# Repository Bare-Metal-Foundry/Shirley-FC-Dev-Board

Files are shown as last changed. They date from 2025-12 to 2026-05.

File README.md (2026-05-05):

<!--
This project follows atomic documentation.
Each subsystem is documented independently.
All configs are stored in YAML.
-->

# Shirley - Flight Controller Development Board

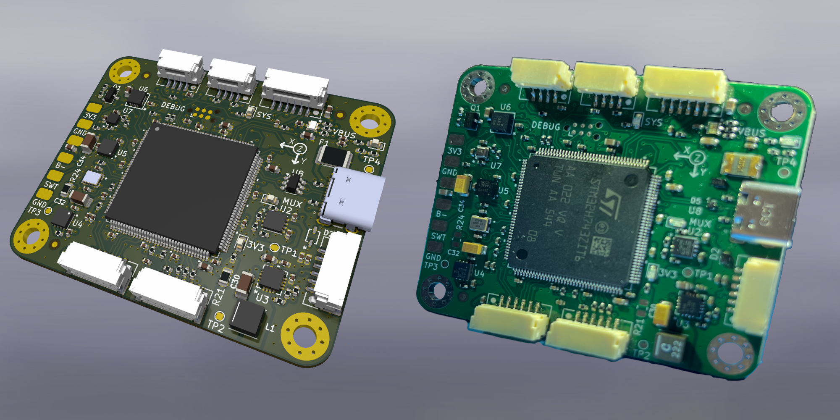
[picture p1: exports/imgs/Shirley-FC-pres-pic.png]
board_render


Shirley is high-performance flight controller hardware platform built around the STM32H743 microcontroller, designed for custom firmware development and compatibility with existing flight stacks.

## Features

### Core Hardware
- **MCU**: STM32H743ZIT6 (480 MHz Cortex-M7, FPU, DSP)
- **IMU**: ICM-40609-D (6-axis, low-noise, up to 32 kHz ODR)
- **Magnetometer**: MMC5983MA (18-bit precision with degaussing)
- **Barometer**: BMP390 High-precision altitude sensing
- **Storage**: SD card socket for flight data logging

### Power System
- **Input**: 5V via standard Pixhawk power module
- **Architecture**: 5V MUX + Dual 3.3V rails (digital + filtered analog) for low-noise sensor operation
- **Protection**: ESD protection on USB-C and power connector

### Connectivity
- **Motor Control**: 4x ESC outputs
- **RC Input**: Standard RC receiver connection
- **GPS**: Dedicated UART interface
- **Telemetry**: Bidirectional radio module support
- **USB**: Full-speed OTG for configuration and debugging
- **CAN**: FDCAN interface (in the GPS connector)
- **Debug**: Tag-Connect SWD/SWO interface

Note: All connectors are GH1.25 connectors

## Documentation

This project uses atomic documentation - each subsystem is documented independently in `/docs`:

- **[Hardware Overview](docs/hardware/overview.md)** - System architecture and block diagrams
- **[Power Architecture](docs/hardware/power-architecture.md)** - Power rail design and specifications
- **[Design Decisions](docs/hardware/design-decisions.md)** - Component selection rationale
- **[STM32 Subsystem](docs/hardware/stm32-subsystem/)** - MCU peripheral configuration

All hardware configurations are defined in machine-readable YAML format in `/config`:
- **[pinout.yaml](config/pinout.yaml)** - Complete STM32H743 pin assignments
- **[power.yaml](config/power.yaml)** - Power rail specifications and architecture

## Repository Structure

```
├── hardware/KiCad/FC_v1.0/         # KiCad 9.0 schematics and PCB layout
├── firmware/STM32 Cube IDE/        # STM32CubeMX configuration
├── config/                         # YAML configuration files
├── docs/                           # Atomic documentation by subsystem
├── docs/hardware/exports/          # exports and version history
└── resources/datasheets/           # Component datasheets organized by type
```

## Getting Started

### Overview
1. Exported schematics and renders can be found here: `exports/`
2. The different versions designed and produced are detailed here: `exports/versions-history.md`
3. An overview of the design can be found here: `docs/hardware/overview.md`

### Hardware Design
1. Open schematics in **KiCad 9.0**: `hardware/KiCad/FC_v1.0/FC-proto.kicad_sch`
2. Review hierarchical subsystem sheets (power, interfaces, sensors)
3. Custom component footprints are in `hardware/cad-layout/`

### Firmware Development
1. Open STM32CubeMX project: `firmware/STM32 Cube IDE/FC-proto-El.ioc`
2. Pin assignments match `config/pinout.yaml`
3. Connect debugger via Tag-Connect cable (SWD: PA13/PA14, SWO: PB3)

## Design Philosophy

This first revision prototype prioritizes:
- **Development-friendly**: Easy debugging via Tag-Connect, USB, and comprehensive logging
- **Compact Board**: Compact board to fit in smaller frames
- **Signal quality**: Low-noise analog power domain for sensor accuracy
- **Integration**: Integration with existing pixhawk drone hardware

## Flight Stack Compatibility

The hardware pinout and peripheral configuration supports:
- **PX4** - Full feature compatibility
- **Ardupilot** - Standard Pixhawk interface support
- **Betaflight** - High-rate control loop capability

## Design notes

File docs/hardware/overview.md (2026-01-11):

# Hardware Overview

## System Architecture

Shirley is a high-performance flight controller development board built around the **STM32H743ZIT6** microcontroller (480 MHz Cortex-M7 with FPU and DSP). The hardware architecture prioritizes signal quality, compact design, and seamless integration with existing Pixhawk drone hardware.

## Core Components

### Microcontroller
- **STM32H743ZIT6**: 480 MHz Cortex-M7, 2 MB Flash, 1 MB RAM
- Complete peripheral assignments in [`config/pinout.yaml`](../../config/pinout.yaml)
- HSE: 16 MHz external crystal oscillator

### Embedded Sensors
- **ICM-40609-D** (IMU): 6-axis low-noise sensor, up to 32 kHz ODR, SPI5 interface
- **MMC5983MA** (Magnetometer): 18-bit precision with built-in degaussing, SPI4 interface
- **BMP390** (Barometer): High-precision altitude sensor, I2C2 interface

See [`docs/hardware/design-decisions.md`](design-decisions.md) for sensor selection rationale.

### Storage
- **SD Card**: SDMMC1 interface (4-bit mode) for flight data logging

## Power Architecture

The power system uses a hierarchical rail structure optimized for low-noise sensor operation:

```
Pixhawk Power Module (5V, 2-3A)
  ├─ EXT_5V → External peripherals (GPS, telemetry) - bypasses MUX
  └─ TPS2113A MUX → 5V_SYS (2.5A, onboard only)
       ├─ TPS62130 Buck → 3V3_DIG (2A) → STM32, peripherals, interfaces
       └─ TPS7A2133 LDO → 3V3_ANA (500mA) → Sensors, STM32 VDDA
```

**Key Design Features:**
- **Dual 3.3V rails**: Separate digital (buck) and analog (LDO) domains
- **5V Power MUX**: The MCU and onboard sensors can be supplied by USB-C, Power connector or both
- **External peripheral bypass**: GPS and telemetry connect directly to EXT_5V, preserving 5V_SYS budget for onboard systems
- **Ultra-low-noise analog**: TPS7A2133 LDO provides 7.7µVRMS noise for precision sensors

Full specifications in [`config/power.yaml`](../../config/power.yaml).

## Peripheral Interfaces

### Power Connector (JST GH 6-pin)
- **Connector**: SM06B-GHS-TB
- **EXT_5V**: Primary power input from Pixhawk power module (5.0V, 2-3A)
- **Battery Monitoring**: Voltage sense (ADC1_INP2: PF11), Current sense (ADC1_INP3: PA6)
- Powers external peripherals directly (GPS, telemetry bypass MUX)

### USB Type-C
- **Interface**: USB_OTG_FS (Full Speed)
- **Pins**: DM: PA11, DP: PA12, VBUS: PA9
- Secondary power input for development/testing

### Debug Tag Connect (TC2030)
- **Interface**: SWD programming and debugging
- **Pins**: SWDIO: PA13, SWCLK: PA14, SWO: PB3
- Tag-Connect 6-pin no-legs connector for compact debugging

### RC Connector (JST GH)
- **Interface**: USART6
- **Pins**: TX: PC6, RX: PC7
- RC receiver input (SBUS, PPM, etc.)

### ESC Connector (JST GH)
- **Interface**: TIM1 (4 channels)
- **Pins**: CH1: PE9, CH2: PE11, CH3: PE13, CH4: PE14
- Motor outputs supporting PWM and DShot protocols

### Telemetry Connector (JST GH)
- **Interface**: UART4 with hardware flow control
- **Pins**: TX: PA0, RX: PA1, CTS: PB0, RTS: PB14
- Telemetry radio communication

### GPS Connector (JST GH)
- **Interfaces**: UART8 + FDCAN1
- **UART8 Pins**: TX: PE1, RX: PE0
- **FDCAN1 Pins**: TX: PB9, RX: PD0
- Supports both serial and CAN GPS modules

### I2C Connector (JST GH)
- **Interface**: I2C1
- **Pins**: SDA: PB7, SCL: PB6
- External I2C peripherals (e.g., external compass)

### Extra Pad Connectors
- **UART5**: TX: PB13, RX: PB12 (Mini Pad Out)
- **USART2**: TX: PA2, RX: PA3 (Pad Out)
- **I2C4**: SDA: PF15, SCL: PF14 (Pad Out)
- **ADC2**: INP2: PF13, INP4: PC4, INP5: PB1 (Analog inputs)
- **GPIOs**: PE15, PB10, PB11 (General purpose expansion)

Complete pin assignments in [`config/pinout.yaml`](../../config/pinout.yaml).

## Connectivity Standards

All connectors use **JST GH 1.25mm** standard (except for debug) for Pixhawk compatibility:
- Power: SM06B-GHS-TB (6-pin)
- Peripherals: Various GH connectors
- Debug: TC2030 (Tag-Connect 6 Pin)

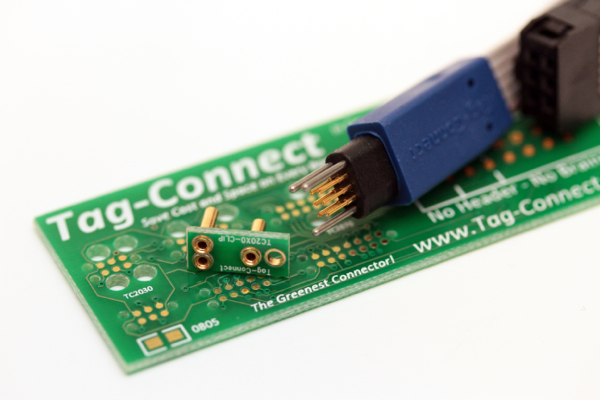
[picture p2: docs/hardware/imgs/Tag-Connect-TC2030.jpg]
tc2030_connector


## Design Priorities

This first revision prototype focuses on:
1. **Signal quality**: Clean analog power domain for sensor accuracy
2. **Development-friendly**: Tag-Connect debugging, USB access, comprehensive logging
3. **Compact form factor**: Fits smaller drone frames
4. **Pixhawk integration**: Standard interfaces and connectors

## Flight Stack Compatibility

The hardware supports multiple flight stacks:
- **PX4**: Full feature compatibility
- **ArduPilot**: Standard Pixhawk interface support
- **Betaflight**: High-rate control loop capability

## Related Documentation

- **[Power Architecture](power-architecture.md)**: Detailed power subsystem design
- **[Design Decisions](design-decisions.md)**: Component selection rationale
- **[STM32 Subsystem](stm32-subsystem/)**: MCU peripheral configuration
- **Configuration Files**: [`pinout.yaml`](../../config/pinout.yaml), [`power.yaml`](../../config/power.yaml)

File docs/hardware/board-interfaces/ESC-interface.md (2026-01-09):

# STM32CubeIDE - Configuring TIM for ESC PWM Control
## Step-by-Step Guide for STM32H743ZIT6

This guide shows you how to configure a timer in STM32CubeIDE to generate 4 PWM signals for ESC motor control.

---

## 📋 Part 1: Opening STM32CubeMX Configuration

### Step 1: Open Your Project
1. Open your project in **STM32CubeIDE**
2. In the Project Explorer, double-click on the **`.ioc`** file
   - Usually named something like `YourProjectName.ioc`
   - This opens the STM32CubeMX graphical configurator

---

## 🎯 Part 2: Selecting and Configuring GPIO Pins

### Step 2: Select Timer Pins in Pinout View

1. You should now see the **Pinout & Configuration** tab
2. Look at the chip diagram in the center

3. **Find and configure the pins for TIM1:**

   **Option A - Click pins directly on chip diagram:**
   - Click on pin **PE9** → Select **TIM1_CH1**
   - Click on pin **PE11** → Select **TIM1_CH2**
   - Click on pin **PE13** → Select **TIM1_CH3**
   - Click on pin **PE14** → Select **TIM1_CH4**

   **Option B - Use the pin assignment tool:**
   - Go to **Pinout view** (left panel)
   - Expand **Timers** → **TIM1**
   - For each channel, click the dropdown:
     - **Channel1** → Select pin **PE9**
     - **Channel2** → Select pin **PE11**
     - **Channel3** → Select pin **PE13**
     - **Channel4** → Select pin **PE14**

4. The pins should now be **green** on the chip diagram, indicating they're configured

### Visual Guide - What You Should See:
```
STM32H743ZIT6 Chip Diagram:
┌─────────────────────────┐
│                         │
│  PE9  (green) ← TIM1_CH1│  Motor 1
│  PE11 (green) ← TIM1_CH2│  Motor 2
│  PE13 (green) ← TIM1_CH3│  Motor 3
│  PE14 (green) ← TIM1_CH4│  Motor 4
│                         │
└─────────────────────────┘
```

---

## ⚙️ Part 3: Timer Configuration

### Step 3: Configure TIM1 in PWM Mode

1. In the **Categories** panel (left side), find and click **Timers** → **TIM1**

2. In the **TIM1 Mode and Configuration** panel, configure each channel:

   **Set Channel Modes:**
   - **Channel 1**: Select **PWM Generation CH1**
   - **Channel 2**: Select **PWM Generation CH2**
   - **Channel 3**: Select **PWM Generation CH3**
   - **Channel 4**: Select **PWM Generation CH4**

   *(Click the dropdown next to each channel and select "PWM Generation CHx")*

### Step 4: Configure Timer Parameters

Now click on the **Parameter Settings** tab (still in TIM1 configuration):

#### Counter Settings:
```
┌─────────────────────────────────────────────┐
│ Parameter              │ Value              │
├─────────────────────────────────────────────┤
│ Prescaler (PSC)        │ 199                │
│ Counter Mode           │ Up                 │
│ Counter Period (ARR)   │ 19999              │
│ Internal Clock Div     │ No Division        │
│ Auto-reload preload    │ Enable             │
└─────────────────────────────────────────────┘
```

**Enter these values:**
- **Prescaler**: `199`
  - *Why?* 200MHz / (199+1) = 1MHz = 1μs tick resolution
- **Counter Period (AutoReload Register)**: `19999`
  - *Why?* 20,000 ticks × 1μs = 20ms = 50Hz (standard for ESC)
- **Counter Mode**: `Up`
- **auto-reload preload**: `Enable`

#### PWM Generation Channel Settings:

For **each channel** (CH1, CH2, CH3, CH4), configure:

```
┌─────────────────────────────────────────────┐
│ Parameter              │ Value              │
├─────────────────────────────────────────────┤
│ Mode                   │ PWM mode 1         │
│ Pulse (CCRx)          │ 1000               │
│ Output Compare Preload │ Enable             │
│ Fast Mode              │ Disable            │
│ CH Polarity            │ High               │
└─────────────────────────────────────────────┘
```

**For Channel 1 (repeat for CH2, CH3, CH4):**
- **Mode**: `PWM mode 1`
- **Pulse (CCR1)**: `1000`
  - *Why?* Starting value = 1000μs = minimum throttle (safe)
- **Output Compare Preload**: `Enable`
- **Fast Mode**: `Disable`
- **CH Polarity**: `High`

### Step 5: Configure Clock Source

1. Still in TIM1 settings, click on **Clock Source** tab
2. Select: **Internal Clock**

### Step 6: Advanced Settings (Important for TIM1!)

TIM1 is an **Advanced Control Timer** and requires additional configuration:

1. Click on **Advanced settings** section (or look for it in the Parameter Settings)

2. Configure **Break and Dead Time**:
   ```
   ┌─────────────────────────────────────────────┐
   │ Off-State Selection for Run    │ Disable   │
   │ Off-State Selection for Idle   │ Disable   │
   │ Lock Configuration             │ OFF       │
   │ Break Input State              │ Disable   │
   │ Automatic Output Enable        │ Disable   │
   └─────────────────────────────────────────────┘
   ```

   **Important**: Make sure **Break Input** is **Disabled** (we don't need it for ESC control)

---

## 🔧 Part 4: Clock Configuration

### Step 7: Verify/Configure System Clock

1. Click on the **Clock Configuration** tab (top of the window)

2. Ensure your **APB2 Timer Clock** is set correctly:
   - Typical for STM32H7: **200 MHz**
   - This is what we used in our prescaler calculation

3. If you need to change it:
   - Adjust the **PLL** settings
   - Adjust **APB2 prescaler**
   - The tool will show you the resulting frequencies

**Target Clock Tree:**
```
HSE (8MHz or 25MHz)
  └→ PLL
      └→ SYSCLK (400MHz typical)
          └→ AHB
              └→ APB2 (200MHz)
                  └→ TIM1 Clock = 200MHz ✓
```

---

## 💾 Part 5: Generate Code

### Step 8: Generate Initialization Code

1. **Save** your configuration: `Ctrl+S` or File → Save

2. Generate code:
   - Click **Project** → **Generate Code**
   - Or press `Alt+K`
   - Or click the **gear icon** ⚙️ in the toolbar

3. A popup will ask if you want to generate code:
   - Click **Yes** or **OK**

4. STM32CubeMX will generate the initialization code in:
   - `main.c` - MX_TIM1_Init() function
   - `stm32h7xx_hal_msp.c` - GPIO and clock initialization

---

## 📝 Part 6: Using the Generated Code

### Step 9: Start PWM in Your Code

The generated code only **initializes** the timer. You need to **start** it!

In your `main.c`, after `MX_TIM1_Init();`, add:

```c
int main(void)
{
  HAL_Init();
  SystemClock_Config();
  MX_GPIO_Init();
  MX_TIM1_Init();        // ← Generated by CubeMX

  /* USER CODE BEGIN 2 */
  
  // START PWM OUTPUT (ADD THIS!)
  HAL_TIM_PWM_Start(&htim1, TIM_CHANNEL_1);
  HAL_TIM_PWM_Start(&htim1, TIM_CHANNEL_2);
  HAL_TIM_PWM_Start(&htim1, TIM_CHANNEL_3);
  HAL_TIM_PWM_Start(&htim1, TIM_CHANNEL_4);
  
  /* USER CODE END 2 */

  while (1)
  {
    /* USER CODE BEGIN 3 */
    
    // Control PWM duty cycle here
    
    /* USER CODE END 3 */
  }
}
```

### Step 10: Control Motor Throttle

To change motor throttle, modify the **CCR (Capture Compare Register)**:

```c
// Set Motor 1 to 1500μs (50% throttle)
__HAL_TIM_SET_COMPARE(&htim1, TIM_CHANNEL_1, 1500);

// Set Motor 2 to 1200μs (20% throttle)
__HAL_TIM_SET_COMPARE(&htim1, TIM_CHANNEL_2, 1200);

// Set Motor 3 to 2000μs (100% throttle)
__HAL_TIM_SET_COMPARE(&htim1, TIM_CHANNEL_3, 2000);

// Set Motor 4 to 1000μs (0% throttle - idle)
__HAL_TIM_SET_COMPARE(&htim1, TIM_CHANNEL_4, 1000);
```

---

## 🎓 Understanding the Configuration

### Why These Values?

**Timer Frequency Calculation:**
```
Timer Input Clock = 200 MHz (from APB2)
Prescaler = 199

Timer Frequency = 200,000,000 / (199 + 1) = 1,000,000 Hz = 1 MHz
Timer Period = 1 / 1,000,000 = 1 μs per tick ✓
```

**PWM Frequency Calculation:**
```
ARR (Period) = 19999
PWM Frequency = Timer Frequency / (ARR + 1)
              = 1,000,000 / 20,000
              = 50 Hz ✓
```

**Pulse Width:**
```
CCR Value = Pulse width in microseconds

Examples:
CCR = 1000 → 1000 μs = 1.0 ms → Minimum throttle
CCR = 1500 → 1500 μs = 1.5 ms → 50% throttle
CCR = 2000 → 2000 μs = 2.0 ms → Maximum throttle
```

---

## 🔍 Verification Checklist

Before testing with motors:

- [ ] All 4 pins (PE9, PE11, PE13, PE14) are green in pinout view
- [ ] TIM1 channels 1-4 set to "PWM Generation CHx"
- [ ] Prescaler = 199
- [ ] Counter Period (ARR) = 19999
- [ ] Initial Pulse (CCR) = 1000 for all channels
- [ ] Break input disabled (for TIM1)
- [ ] Code generated successfully
- [ ] HAL_TIM_PWM_Start() called for all channels
- [ ] Project compiles without errors

---

## 🎯 Quick Reference Table

| Setting | Value | Purpose |
|---|---|---|
| Timer | TIM1 | Advanced timer with 4 channels |
| Pins | PE9, PE11, PE13, PE14 | PWM outputs |
| Prescaler | 199 | Get 1μs resolution |
| ARR | 19999 | 20ms period = 50Hz |
| CCR Initial | 1000 | Start at min throttle (safe) |
| CCR Range | 1000-2000 | Standard ESC range |
| PWM Mode | Mode 1 | Active when CNT < CCR |
| Polarity | High | Active high output |

---

## 🐛 Common Issues & Solutions

### Issue 1: No PWM Output
**Check:**
- Did you call `HAL_TIM_PWM_Start()`?
- Are GPIO clocks enabled? (Should be automatic)
- Is TIM1 clock enabled? (Should be automatic)
- Check with oscilloscope or logic analyzer

### Issue 2: Wrong Frequency
**Check:**
- Verify APB2 timer clock in Clock Configuration tab
- Recalculate prescaler if clock is different from 200MHz
- Formula: `Prescaler = (Timer_Clock / 1,000,000) - 1`

### Issue 3: ESC Not Responding
**Check:**
- Ground connection between STM32 and ESC
- CCR value is in range 1000-2000
- ESC is powered from battery
- Some ESCs need calibration first

### Issue 4: CubeMX Won't Generate Code
**Check:**
- Resolve any warnings (yellow triangles)
- Check for pin conflicts (red pins)
- Save the .ioc file first

---

## 🔧 Alternative Timer Options

If TIM1 pins are not available, you can use other timers:

### TIM2, TIM3, TIM4, TIM5, TIM8
- **TIM2**: General-purpose, 32-bit (more resolution if needed)
- **TIM3, TIM4, TIM5**: General-purpose, simpler than TIM1
- **TIM8**: Another advanced timer (similar to TIM1)

**To use TIM3 instead:**
1. Select TIM3 in Categories
2. Choose 4 pins that support TIM3_CHx
3. Use same prescaler/ARR values
4. No "Break" configuration needed (simpler!)

---

## 📸 Visual Guide Screenshots Description

When configuring, you should see:

**1. Pinout View:**
- Chip diagram with PE9, PE11, PE13, PE14 highlighted in green
- Each pin labeled with TIM1_CH1, TIM1_CH2, etc.

**2. TIM1 Configuration:**
- Left panel: TIM1 selected under Timers
- Right panel: Mode and Configuration
- All 4 channels showing "PWM Generation CHx"

**3. Parameter Settings:**
- Counter Settings section with PSC=199, ARR=19999
- Four channel configurations with CCR=1000

**4. Clock Configuration:**
- Clock tree showing path to TIM1
- APB2 timer clock = 200MHz

## 📚 Additional Resources

**STM32 Documentation:**
- RM0433: STM32H743 Reference Manual (Timer chapter)
- AN4776: General-purpose timer cookbook
- STM32CubeIDE User Guide

**ESC Resources:**
- Most ESCs expect 50Hz (some support 400Hz)
- 1000μs = min, 2000μs = max (standard)
- Always test without propellers first!

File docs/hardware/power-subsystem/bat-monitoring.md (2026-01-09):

# Voltage & Current Measurement (Pixhawk Power Connector → STM32H7)

## 1. Overview

The Pixhawk-style **POWER** connector exposes two **analog** signals:

- **VOLTAGE**: battery voltage via a resistor divider (max ≈ 3.3 V)
- **CURRENT**: load current via a current-sense circuit (max ≈ 3.3 V)

These are read by the STM32H7’s ADC as **single-ended analog inputs**.

> ⚠ The exact scaling (divider ratio & A/V gain) depends on the power module.
> Check its datasheet for numerical values.

---

## 2. Hardware Connections

Assuming use of **ADC1 Channel 2 & 3** (example):

- `POWER.VOLTAGE` → MCU pin mapped to **ADC1_IN2** (Rank 1)
- `POWER.CURRENT` → MCU pin mapped to **ADC1_IN3** (Rank 2)
- GND of the power module tied to MCU analog GND
- Optional small RC filters at the MCU pins (e.g. 1–4.7 kΩ + 100 nF to GND)

All signals stay within **0 – 3.3 V** (ADC reference range).

---

## 3. STM32CubeIDE ADC Configuration (ADC1)

**Global settings**

- Resolution: **12 bits**
- Scan Conversion Mode: **Enabled**
- Continuous Conversion Mode: **Enabled**
- Discontinuous Mode: **Disabled**
- End of Conversion Selection: **End of single conversion**
- Overrun behaviour: **Overrun data preserved**
- Conversion Data Management: **Regular Conversion data stored in DR**

**Regular Conversion Mode**

- Enable Regular Conversions: **Enabled**
- Number Of Conversions: **2**
- External Trigger Source: **Regular Conversion launched by software**
- External Trigger Edge: **None**

**Ranks**

- Rank 1  
  - Channel: **Channel 2** (ADC1_IN2 → VOLTAGE)  
  - Sampling Time: **64.5 Cycles**  
  - Offset: **None**
- Rank 2  
  - Channel: **Channel 3** (ADC1_IN3 → CURRENT)  
  - Sampling Time: **64.5 Cycles**  
  - Offset: **None**

(Other channels: **Disabled**, Single-ended mode.)

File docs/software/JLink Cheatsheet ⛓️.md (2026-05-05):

# JLink Cheatsheet ⛓️

Here we detail steps on how to use basic commands from the JLink Commander software.

> [!info] These are usefull steps to check if the MCU is working properly.
## Download and run

You can download `SEGGER J-Link Commander Vx.xx`from the web and then run in the terminal with:

```bash
JLinkExe
```

Note: Done on MacOS 
## Start a connection

Once JLink Commander launched you can connect to your MCU:

```
connect
```
 It will then ask for:
 - **Device**: STM32H743ZI
 - **Interface**: SWD
 - **Speed**: 1000 (for starting safe)

## Halt the CPU

You can halt the CPU :
```
halt
```

## Read registers

To read CPU registers
```
r
```

You’ll see values like:

```
R0 = 0x...PC = 0x...
```

## Read memory

### Flash:

```
mem32 0x08000000 4
```

### SRAM:

```
mem32 0x20000000 4
```

👉 If this works:

- Bus matrix OK
- Memory accessible
- Core not locked

## Erase flash

```
erase
```

👉 If it succeeds:

- Flash interface works
- Power is stable enough

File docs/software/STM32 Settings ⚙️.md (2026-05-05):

# STM32 Settings ⚙️

## Clock config ⏱️

RCC:
- HSE: Crystal Resonator

### Config for max frequency of 480Mhz
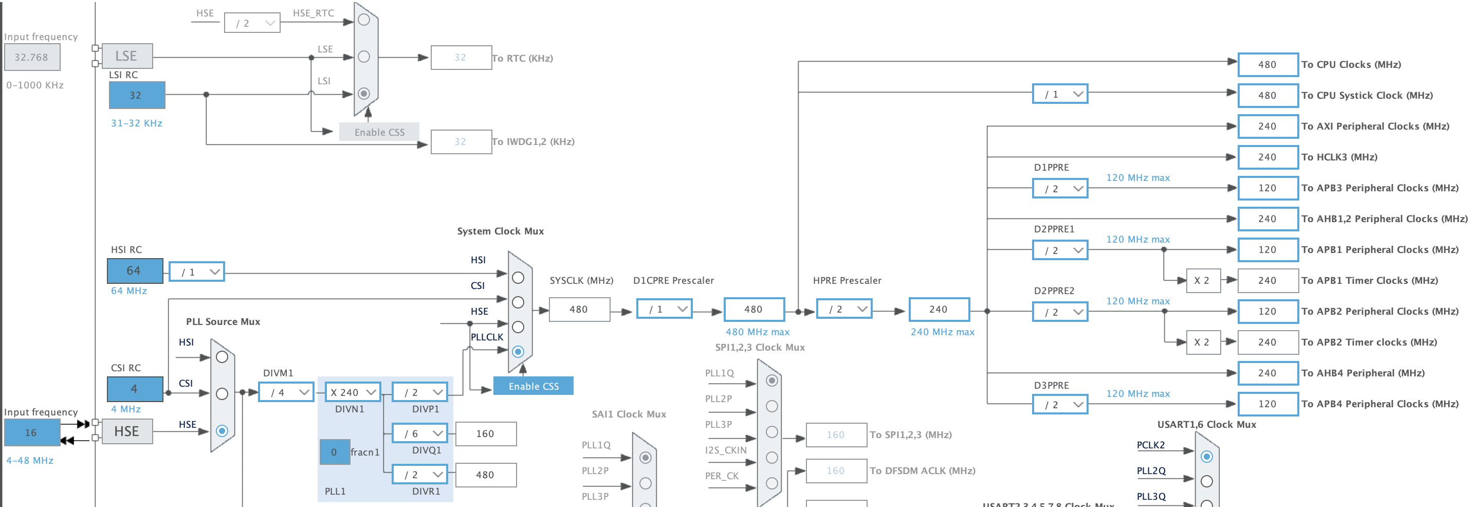
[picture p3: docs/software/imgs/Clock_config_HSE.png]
clock_config_HSE


### Config for first bringup
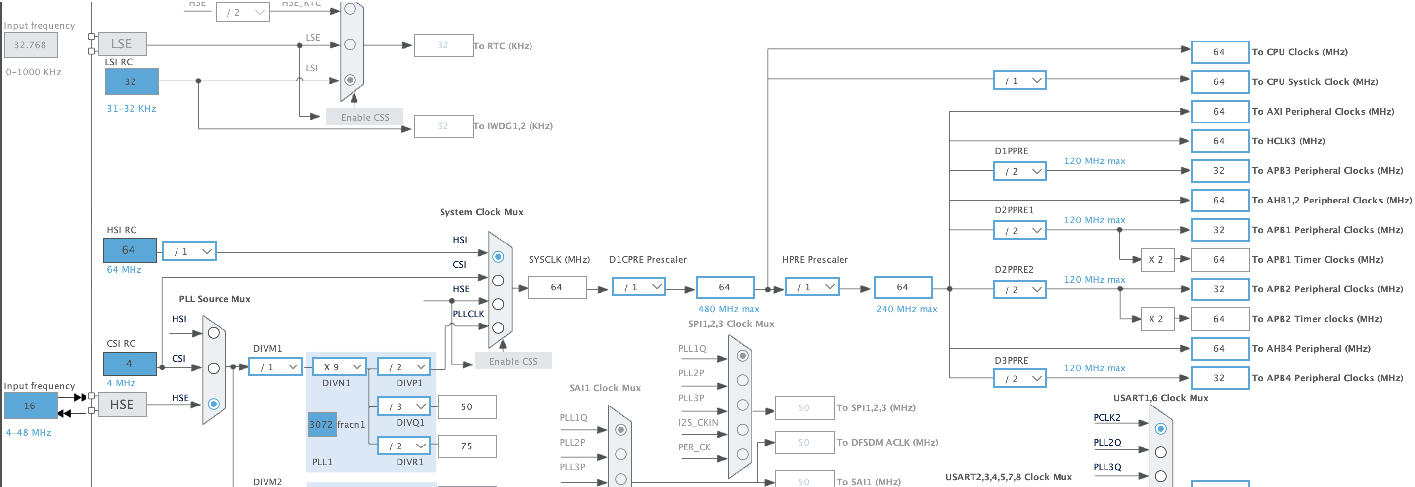
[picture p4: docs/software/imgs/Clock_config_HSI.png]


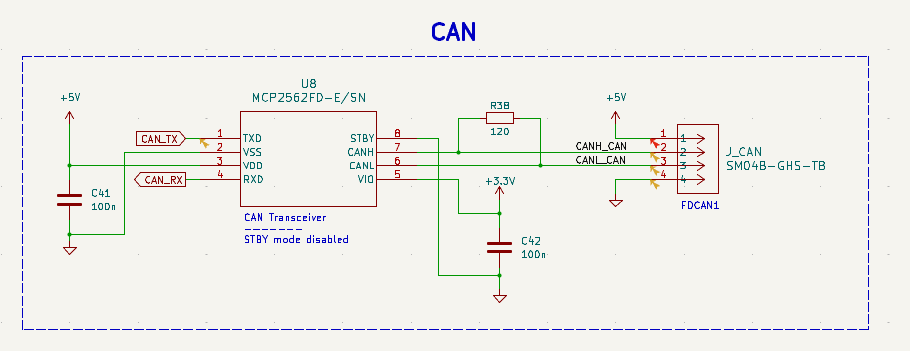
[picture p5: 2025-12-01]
docs/hardware/board-interfaces/imgs/CAN-Circuit.png

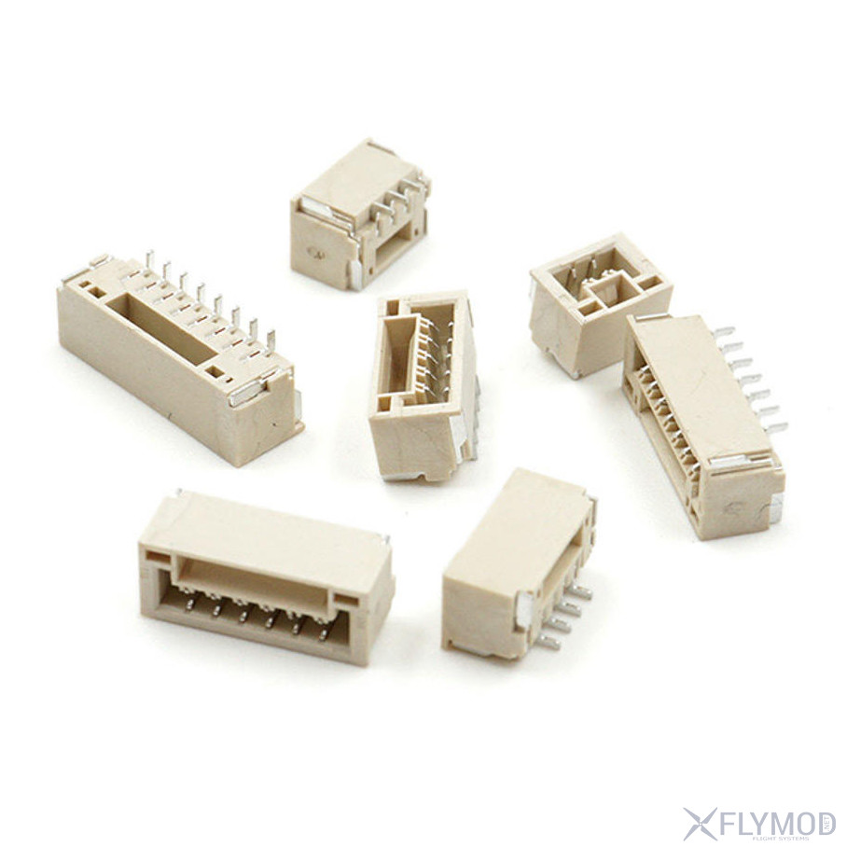
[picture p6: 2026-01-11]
docs/hardware/imgs/GH1.25-connectors.jpg

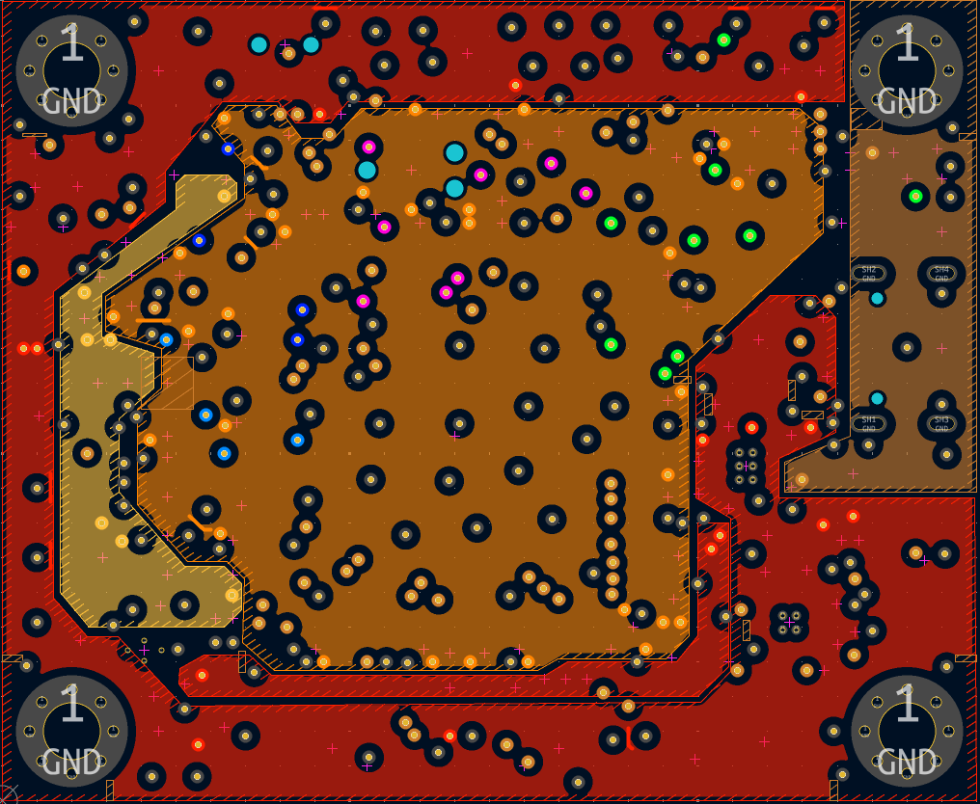
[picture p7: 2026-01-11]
exports/imgs/FC-Shirley-v0.7-In2Layer.png

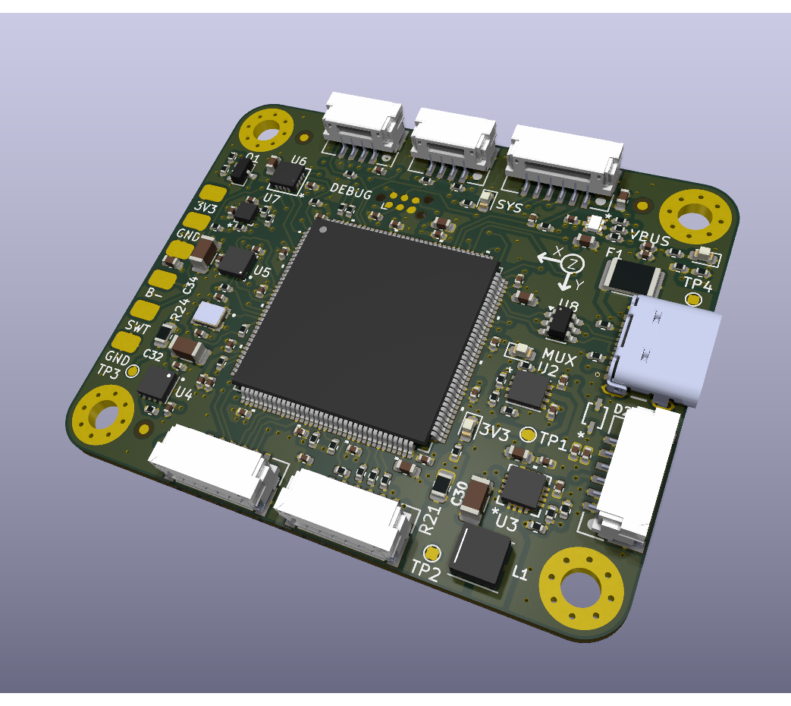
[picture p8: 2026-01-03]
exports/imgs/FC-Shirley-v0.7-topview.png

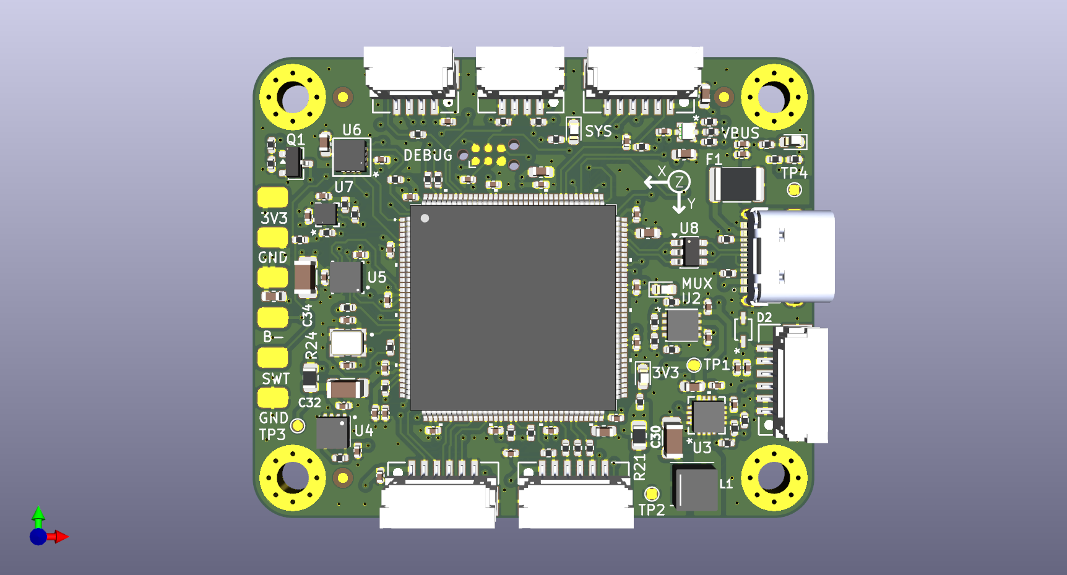
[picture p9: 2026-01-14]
exports/imgs/FC-Shirley-v0.7-S-topview.png

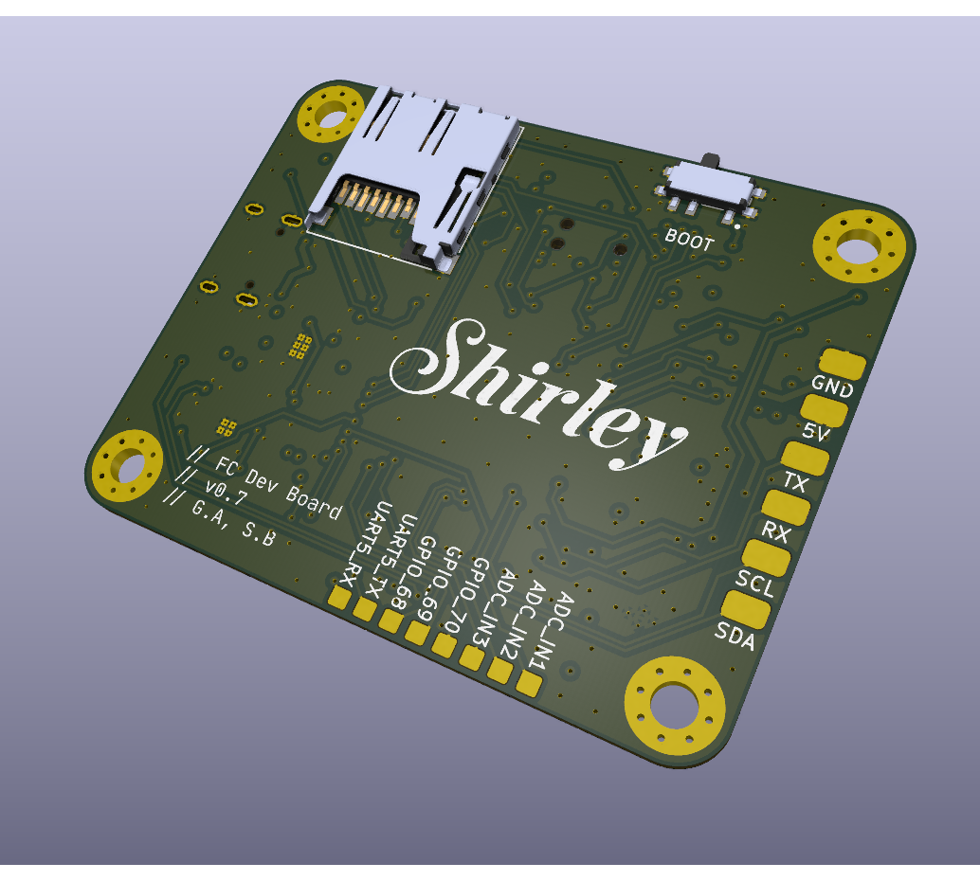
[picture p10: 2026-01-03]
exports/imgs/FC-Shirley-v0.7-botview.png

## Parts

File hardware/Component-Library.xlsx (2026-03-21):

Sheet: ICs
Category | Component | Description |  |  | Boards |  | Suppliers
 |  | Package | Datasheet | Comment | proto v1.0 | v2.0 | JLCPCB | DigiKey
SENSOR
IMU | ICM-42688-P |  | ..\resources\datasheets\IMU\ds-000347_icm-42688-p-datasheet.pdf | best noise / ODR 32kHz | no | yes | JLCPCB-ICM-42688 (https://jlcpcb.com/parts/componentSearch?searchTxt=ICM-42688-P) | DigiKey-ICM-42688 (https://www.digikey.com.au/en/products/detail/tdk-invensense/ICM-42688-P/10824934)
 | BMI088 |  | ..\resources\datasheets\IMU\bst-bmi088-ds001.pdf | Best reliability max acc 24g | no | yes |  | DigiKey-BMI088 (https://www.digikey.com/en/products/detail/bosch-sensortec/BMI088/8634936)
 | ICM-40609-D | 24-VFLGA (3x3) | ..\resources\datasheets\IMU\DS-000330-ICM-40609-D-v1.2.pdf | ODR 32kHz max 32g | yes | no | JLCPCB-ICM-40609-D (https://jlcpcb.com/partdetail/TDKInvenSense-ICM_40609D/C5360621) | DigiKey-ICM-40609-D (https://www.digikey.com/en/products/detail/tdk-invensense/ICM-40609-D/19200630)
MAG | MMC5983MA |  | ..\resources\datasheets\MAG\MMC5983MADatasheetRevA.pdf | best heading | yes | yes | DigiKey-MMC5983MA (https://www.digikey.com.au/en/products/detail/memsic-inc/MMC5983MA/10452795) | JLCPCB-MMC5983MA (https://jlcpcb.com/partdetail/MEMSIC-MMC5983MA/C404329)
 | BMM350 |  | ..\resources\datasheets\MAG\bst-bmm350-ds001.pdf | reliable | no | ?
BAR | MS5611-01BA03 |  | ..\resources\datasheets\BAR\ENG_DS_MS5611-01BA03_B3.pdf |  | no | yes
 | BMP388 |  | ..\resources\datasheets\BAR\BMP388.pdf | 8 Pa precision +-0,66m | yes |  |  | JLCPCB-BMP388 (https://jlcpcb.com/partdetail/BoschSensortec-BMP388/C779278)
 | BMP390 |  | ..\resources\datasheets\BAR\bst-bmp390-ds002.pdf | 3 Pa precision +-0,25m | no | yes | DigiKey-BMP390 (https://www.digikey.com.au/en/products/detail/bosch-sensortec/BMP390/16164575) | JLCPCB-BMP390 (https://jlcpcb.com/partdetail/BoschSensortec-BMP390/C5124834)
COMPUTING
MCU | STM32H743ZIT6 | LQFP-144 | ..\resources\datasheets\STM32\Datasheet\STM32H743xI-G.pdf |  | yes | no | STM32H743ZIT6 (https://jlcpcb.com/partdetail/STMicroelectronics-STM32H743ZIT6/C114408) | DigiKey-STM32H743ZIT (https://www.digikey.com.au/en/products/detail/stmicroelectronics/STM32H743ZIT6/7809238)
 | STM32H753 |  |  |  | yes | no
 | STM32H757 |  |  | dual core | yes | no
POWER
MUX | TPS2113ADRBR | 8-VDFN Exposed Pad (3x3) | ..\resources\datasheets\POWER\TPS2113a.pdf | 5V Mux 2A max | yes | no |  | DigiJey-TPS2113A (https://www.digikey.com.au/en/products/detail/texas-instruments/TPS2113ADRBR/2353703)
LDO | TPS7A2133PQWDRBRQ1 | 8-VDFN Exposed Pad (3x3) | ..\resources\datasheets\LDO\tps7a21-q1.pdf | Automotive, 500mA, Low-Noise, Low-IQ, High-PSRR LDO | yes |  | JLCPCB-TPS7A2133 (https://jlcpcb.com/partdetail/22705404-TPS7A2133PQWDRBRQ1/C21285173) | DigiKey-TPS7A2133 (https://www.digikey.com.au/en/products/detail/texas-instruments/TPS7A2133PQWDRBRQ1/21600665)
 | NR1644GA040AE4S |  | ..\resources\datasheets\LDO\nr1644-s-e.pdf | Low Noise High RR Low Dropout | no |  |  | DigiKey-NR1644GA (https://www.digikey.com.au/en/products/detail/nisshinbo-micro-devices-inc/NR1644GA040AE4S/26460066)
 | TPS7A4700RGWT |  |  | 1-A, 4-μVRMS, RF LDO | no |  | JLCPCB-TPS7A4700 (https://jlcpcb.com/partdetail/TexasInstruments-TPS7A4700RGWT/C28286) | DigiKey-TPS7A4700 (https://www.digikey.com.au/en/products/detail/texas-instruments/TPS7A4700RGWT/3516858)
BUCK | TPS62130ARGTR | 16-VFQFN Exposed Pad (https://www.digikey.com.au/en/products/filter/power-management-pmic/voltage-regulators-dc-dc-switching-regulators/16-vfqfn-exposed-pad/739) | ..\resources\datasheets\POWER\TPS62130.pdf |  | yes | no | JLCPCB-TPS62130 (https://jlcpcb.com/partdetail/TexasInstruments-TPS62130ARGTR/C337502) | DigiKey-TPS62130 (https://www.digikey.com.au/en/products/detail/texas-instruments/TPS62130ARGTR/4307640)
TRANSCEIVER
CAN | MCP2562FD-E/SN | 8-SOIC (0.154", 3.90mm Width) | ..\resources\datasheets\CAN\MCP2561-2FD-datasheet.pdf | convert CAN TX/RX to H/L | no |  | JLCPCB-MCP2562FD (https://jlcpcb.com/partdetail/MicrochipTech-MCP2562FD_ESN/C124016) | DigiKey-MCP2562FD (https://www.digikey.com.au/en/products/detail/microchip-technology/MCP2562FD-E-SN/4842808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)
 | MCP2562FDT-E/MF | 8-VDFN Exposed Pad |  |  | no |  |  | DijiKey-MPC2562FDF (https://www.digikey.com.au/en/products/detail/microchip-technology/MCP2562FDT-E-MF/4860104)

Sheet: Standard components
Category | Component | Description |  |  | Boards |  | Suppliers
 |  | Package | Datasheet | Comment | proto v1.0 | v2.0 | JLCPCB | DigiKey
LED | 19-337C/RSBHGHC-A88/4T | 0606 (1616 Metric) | ..\resources\datasheets\LED\Everlight 19-337C.pdf | RGB LED | yes | yes | JLCPCB-19-337C (https://jlcpcb.com/partdetail/3536968-19_337C_RSBHGHC_A884T/C3019536) | DigiKey-19-337C (https://www.digikey.com.au/en/products/detail/everlight-electronics-co-ltd/19-337C-RSBHGHC-A88-4T/10059590)
 | KT-0603R | 0603 | ..\resources\datasheets\LED\KT-0603R.pdf | Red LED | yes |  | JLCPCB-KT0603R (https://jlcpcb.com/partdetail/Hubei_KENTOElec-KT0603R/C2286)
 | KT-0603W | 0603 | ..\resources\datasheets\LED\KT-0603W.pdf | White yellow LED | no |  | JLCPCB-KT0603W (https://jlcpcb.com/partdetail/Hubei_KENTOElec-KT0603W/C2290)
 | LTST-C150EKT | 1206 (3216 Metric) | ..\resources\datasheets\LED\LTST-C150EKT.pdf | Red LED | no | no |  | DigiKey-LTST-C150EKT (https://www.digikey.com.au/en/products/detail/liteon/LTST-C150EKT/269215)
 | LTST-C150GKT | 1206 (3216 Metric) | ..\resources\datasheets\LED\LTST-C150GKT.pdf | Green LED | no | no | JLCPCB-LTST-C150EKT (https://jlcpcb.com/partdetail/LiteOn-LTSTC150GKT/C125084) | DigiKey-LTST-C150GKT (https://www.digikey.com.au/en/products/detail/liteon/LTST-C150GKT/269216)
 | LTST-C191KGKT | 0603 (1608 Metric) | ..\resources\datasheets\LED\LTST-C191KGKT.PDF | Green LED | no | yes |  | DigiKey-LTST-C161KGKT (https://www.digikey.com.au/en/products/detail/liteon/LTST-C191KGKT/386835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)
CRYSTAL | X322516MLB4SI | SMD3225-4P | ..\resources\datasheets\CRYSTAL\X322516M.pdf | 16MHz 9pF Crystal Oscillator ±10ppm ±20ppm | yes |  | JLCPCB-X322516M (https://jlcpcb.com/partdetail/YXC_CrystalOscillators-X322516MLB4SI/C13738)
 | TSX-3225 16.0000MF18X-AC3 | 4-SMD (3.2x2.5) | ..\resources\datasheets\CRYSTAL\TSX-3225_en.pdf | 16MHz 9pF 60 Ohms | yes |  | JLCPCB-TSX-3225 (https://jlcpcb.com/partdetail/2078519-TSX_3225_16_0000MF18XAC3/C1986974) | DigiKey-TSX3225 (https://www.digikey.com.au/en/products/detail/epson/TSX-3225-16-0000MF18X-AC3/1825445)
SWITCH | PCM12SMTR |  | ..\resources\datasheets\SWITCH\C221841.pdf | 6V | yes |  | JLCPCB-PCM12SMTR (https://jlcpcb.com/partdetail/CK-PCM12SMTR/C221841) | DigiKey-PCM12SMTR (https://www.digikey.com.au/en/products/detail/c-k/PCM12SMTR/1640112)
 | CUS-12TB |  | ..\resources\datasheets\SWITCH\CUS-12TB.pdf | 4V | no |  | JLCPCB-CUS-12TB (https://jlcpcb.com/partdetail/Nidec-CUS12TB/C2921739) | DigiKey-CUS-12TB (https://www.digikey.com.au/en/products/detail/nidec-components-corporation/CUS-12TB/1124222)
CAP | CL05C100JB5NNNC | 0402 |  | 10pF |  |  |  | DigiKey-MLCC10pF (https://www.digikey.com/en/products/detail/samsung-electro-mechanics/CL05C100JB5NNNC/3886797)
 | CL05B103KB5NNNC | 0402 |  | 10nF | yes |  |  | DigiKey-MLCC10nF (https://www.digikey.com.au/en/products/detail/samsung-electro-mechanics/CL05B103KB5NNNC/3886686)
 | CL05B332KB5NNNC | 0402 |  | 3.3nF | yes |  | JLCPCB-MLCC3.3nF-0402 (https://jlcpcb.com/partdetail/27148-CL05B332KB5NNNC/C26404)
 | CL10B332KB8NNNC | 0603 |  | 3.3nF | no |  | JLCPCB-MLCC3.3nF (https://jlcpcb.com/partdetail/1965-CL10B332KB8NNNC/C1613)
 | CL05B104KO5NNNC | 0402 (1005 Metric) |  | 100nF MLCC X7R | yes |  | JLCPCB-MLCC100nF (https://jlcpcb.com/partdetail/1877-CL05B104KO5NNNC/C1525)
 | CL05A105KA5NQNC | 0402 (1005 Metric) |  | 1 uF X5R | yes |  | JLCPCB-MLCC1uF (https://jlcpcb.com/partdetail/53938-CL05A105KA5NQNC/C52923)
 | CL10A225KO8NNNC | 0603 |  | 2,2uF MLCC | yes |  | JLCPCB-MLCC2.2uF (https://jlcpcb.com/partdetail/24366-CL10A225KO8NNNC/C23630)
 | CL10A106MA8NRNC | 0603 |  | 10 uF | yes |  | JLCPCB-MLCC10uF (https://jlcpcb.com/partdetail/97651-CL10A106MA8NRNC/C96446)
 | CL21A226MAQNNNE | 0805 |  | 22uF MLCC | yes |  | JLCPCB-MLCC22uF (https://jlcpcb.com/partdetail/46786-CL21A226MAQNNNE/C45783)
 | TAJA225K016RNJ | 1206 |  | 2,2uF Tantalum 16V | yes |  | JLCPCB-TAJA225K016 (https://jlcpcb.com/partdetail/-TAJA225K016RNJ/C7180)
 | T491A106K010AT | 1206 (3216 Metric) |  | 10 uF Tantalum | yes |  | JLCPCB-T491A106 (https://jlcpcb.com/partdetail/KEMET-T491A106K010AT/C1508940) | DigiKey-T491A106 (https://www.digikey.com.au/en/products/detail/kemet/T491A106K010AT/818545)
 | TAJA226M016RNJ | 1206 (3216 Metric) |  | 22 uF Tantalum 16V | yes |  | JLCPCB-TAJA226 (https://jlcpcb.com/partdetail/-TAJA226M016RNJ/C6328904) | DigiKey-TAJA226 (https://www.digikey.com.au/en/products/detail/kyocera-avx/TAJA226M016RNJ/10381501)
RES | 0805W8F0000T5E | 0805 |  | 0Ω | yes |  | JLCPCB-R0-0805 (https://jlcpcb.com/partdetail/18165-0805W8F0000T5E/C17477)
 | 0402WGF0000TCE | 0402 |  | 0Ω | yes |  | JLCPCB-R0-0402 (https://jlcpcb.com/partdetail/17853-0402WGF0000TCE/C17168)
 | 0402WGF330JTCE | 0402 |  | 33Ω | yes |  | JLCPCB-R33-0402 (https://jlcpcb.com/partdetail/25848-0402WGF330JTCE/C25105)
 | 0402WGF499JTCE | 0402 |  | 50Ω | yes |  | JLCPCB-R50-0402 (https://jlcpcb.com/partdetail/25863-0402WGF499JTCE/C25120)
 | 0402WGF1000TCE | 0402 |  | 100Ω | yes |  | JLCPCB-R100-0402 (https://jlcpcb.com/partdetail/25819-0402WGF1000TCE/C25076)
 | 0402WGF2200TCE | 0402 |  | 220Ω | yes |  | JLCPCB-R220-0402 (https://jlcpcb.com/partdetail/25834-0402WGF2200TCE/C25091)
 | 0402WGF1001TCE | 0402 |  | 1k | yes |  | JLCPCB-R1k-0402 (https://jlcpcb.com/partdetail/12256-0402WGF1001TCE/C11702)
 | 0402WGF1501TCE | 0402 |  | 1,5k | yes |  | JLCPCB-R1.5k-0402 (https://jlcpcb.com/partdetail/26610-0402WGF1501TCE/C25867)
 | 0402WGF2201TCE | 0402 |  | 2,2k | yes |  | JLCPCB-R2.2k-0402 (https://jlcpcb.com/partdetail/26622-0402WGF2201TCE/C25879)
 | 0402WGF4701TCE | 0402 |  | 4,7k | yes |  | JLCPCB-R4.7k-0402 (https://jlcpcb.com/partdetail/26643-0402WGF4701TCE/C25900)
 | 0402WGF5101TCE | 0402 |  | 5,1k | yes |  | JLCPCB-R5.1k-0402 (https://jlcpcb.com/partdetail/26648-0402WGF5101TCE/C25905)
 | 0402WGF1002TCE | 0402 |  | 10k | yes |  | JLCPCB-R10k-0402 (https://jlcpcb.com/partdetail/26487-0402WGF1002TCE/C25744)
 | 0402WGF4702TCE | 0402 |  | 47k | no |  | JLCPCB-R47k-0402 (https://jlcpcb.com/partdetail/26535-0402WGF4702TCE/C25792)
 | 0402WGF5102TCE | 0402 |  | 51k | yes |  | JLCPCB-R51k-0402 (https://jlcpcb.com/partdetail/26537-0402WGF5102TCE/C25794)
 | 0402WGF5102TCE | 0402 |  | 100k | yes |  | JLCPCB-R100k-0402 (https://jlcpcb.com/partdetail/26484-0402WGF1003TCE/C25741)
IND | XFL4020-222MEC | 1616 (4040 Metric) | ..\resources\datasheets\IND\xfl4020.pdf | FIXED IND 2.2UH 8A 23.5MOHM SM | yes |  | JLCPCB-XFL4020-222 (https://jlcpcb.com/partdetail/Coilcraft-XFL4020222MEC/C122469) | DigiKey-XFL4020-222 (https://www.digikey.com.au/en/products/detail/coilcraft/XFL4020-222MEC/21381254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)
ESD | TPD2EUSB30ADRTR | SOT-23-3 Variant | ..\resources\datasheets\ESD\tpd2eusb30a.pdf | TVS DIODE 3.6VWM 8VC | yes |  | JLCPCBs-TPD2EUSB30A (https://jlcpcb.com/partdetail/TexasInstruments-TPD2EUSB30ADRTR/C94934) | DigiKey-TPD2EUSB30A (https://www.digikey.com.au/en/products/detail/texas-instruments/TPD2EUSB30ADRTR/2520830)
 | USBLC6-2SC6 | SOT-23-6 | ..\resources\datasheets\ESD\USBLC6-2-datasheet.pdf | For self powered devices TVS DIODE 5.25VWM 17VC | yes |  | JLCPCB-USBLC6 (https://jlcpcb.com/partdetail/STMicroelectronics-USBLC62SC6/C7519) | DigiKey-USBLC6 (https://www.digikey.com.au/en/products/detail/stmicroelectronics/USBLC6-2SC6/1040559)
 | TPD4E05U06DQAR | 10-UFDFN (2.5x1) | ..\resources\datasheets\ESD\tpd4e05u06.pdf | TVS DIODE 5.5VWM 14VC 10USON | no |  | JLCPCB-TPD4E05 (https://jlcpcb.com/partdetail/TexasInstruments-TPD4E05U06DQAR/C138714) | DigiKey-TPD4E05 (https://www.digikey.com/en/products/detail/texas-instruments/TPD4E05U06DQAR/3996774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)
 | LTVS16H5.0T5G | DFN1610-2 | ..\resources\datasheets\ESD\LTVS16H5.pdf | 100A@8/20us 2uA 5V 7.8V 8.5V 15V 800pF ESD Unidirectional | yes |  | JLCPCB-LTVS16H5 (https://jlcpcb.com/partdetail/LRC-LTVS16H50T5G/C172440)
 | TSD05DYFR | SC-76, SOD-323 | ..\resources\datasheets\ESD\tsd05.pdf | TVS DIODE 5.5VWM 9VC SOD-323 | no |  | JLCPCB-TSD05 (https://jlcpcb.com/partdetail/TexasInstruments-TSD05DYFR/C22396185) | DigiKey-TSD05 (https://www.digikey.com/en/products/detail/texas-instruments/TSD05DYFR/21298352)
FUSE | MF-MSMF050-2 | 1812 (4532 Metric), Concave | ..\resources\datasheets\FUSE\mf-msmf.pdf | Polymeric PTC Resettable Fuse 15V 500 mA | yes |  | JLCPCB-MF-MSMF050 (https://jlcpcb.com/partdetail/BOURNS-MF_MSMF0502/C17313) | DigiKey-MF-MSMF050 (https://www.digikey.com.au/en/products/detail/bourns-inc/MF-MSMF050-2/662816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)
MOSFET | 2N7002 | SOT-23-3 (TO-236) | ..\resources\datasheets\MOSFET\Diotec-2n7002.pdf | MOSFET N-CH 60V 280MA | no |  |  | DigiKey-2N7002 (https://www.digikey.com.au/en/products/detail/diotec-semiconductor/2N7002/13163336)
 | AO3400A | 3-SMD, SOT-23-3 Variant (https://www.digikey.com.au/en/products/filter/transistors/fets-mosfets/single-fets-mosfets/3-smd-sot-23-3-variant/278) | ..\resources\datasheets\MOSFET\AO3400A_ds.pdf | N-Channel 30 V 5.7A (Ta) 1.4W (Ta | yes |  | JLCPCB-AO3400A (https://jlcpcb.com/partdetail/Alpha_OmegaSemicon-AO3400A/C20917) | DigiKey-AO3400A (https://www.digikey.com.au/en/products/detail/alpha-omega-semiconductor-inc/AO3400A/1855772)
FB | BLM18KG102SN1D |  |  |  | no

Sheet: Interfaces
Category | Component | Description |  |  | Boards |  | Suppliers
 |  | Package | Datasheet | Comment | proto v1.0 | v2.0 | JLCPCB | DigiKey
MEM | MEM2061-01-188-00-A |  | ..\resources\datasheets\SD_CARD\mem2061-spec.pdf | micro SD card socket | yes | yes | JLCPCB-MEM2061 (https://jlcpcb.com/partdetail/5778033-MEM2061_01_188_00A/C5151738) | DigiKey-MEM2061 (https://www.digikey.com.au/en/products/detail/gct/MEM2061-01-188-00-A/9859612)
USB-C | USB4105-GF-A |  | ..\resources\datasheets\USB-C\usb4105-drawing.pdf |  | yes | yes | JLCPCB-USB4105 (https://jlcpcb.com/partdetail/3554049-USB4105_GF_A060/C3025063) | DigiKey-USB4105 (https://www.digikey.com.au/en/products/detail/gct/USB4105-GF-A/11198441)
CONNECTOR | SM04B-GHS-TB |  | ..\resources\datasheets\CONNECTOR\GH1.25-datasheet.pdf | GH1,25 4 pins | yes |  |  | DigiKey-SM04B-GHS (https://www.digikey.com.au/en/products/detail/jst-sales-america-inc/SM04B-GHS-TB/807788)
 | SM03B-GHS-TB |  | ..\resources\datasheets\CONNECTOR\GH1.25-datasheet.pdf | GH1,26 3pins | no |  |  | DigiKey-SM03B-GHS (https://www.digikey.com.au/en/products/detail/jst-sales-america-inc/SM03B-GHS-TB/807787)
 | SM06B-GHS-TB |  | ..\resources\datasheets\CONNECTOR\GH1.25-datasheet.pdf | GH1,26 6pins | yes |  |  | DigiKey-SM6B-GHS (https://www.digikey.com.au/en/products/detail/jst-sales-america-inc/SM06B-GHS-TB/807790)
 | FTSH-105-01-F-DV-K |  |  | 10 pin 1,27 for Cortex-M Debug | no |  | JLCPCB-FTSH-105 (https://jlcpcb.com/partdetail/Samtec-FTSH_105_01_L_DVK/C5155080) | DigiKey-FTSH-105 (https://www.digikey.com.au/en/products/detail/samtec-inc/FTSH-105-01-F-DV-K/2649974)

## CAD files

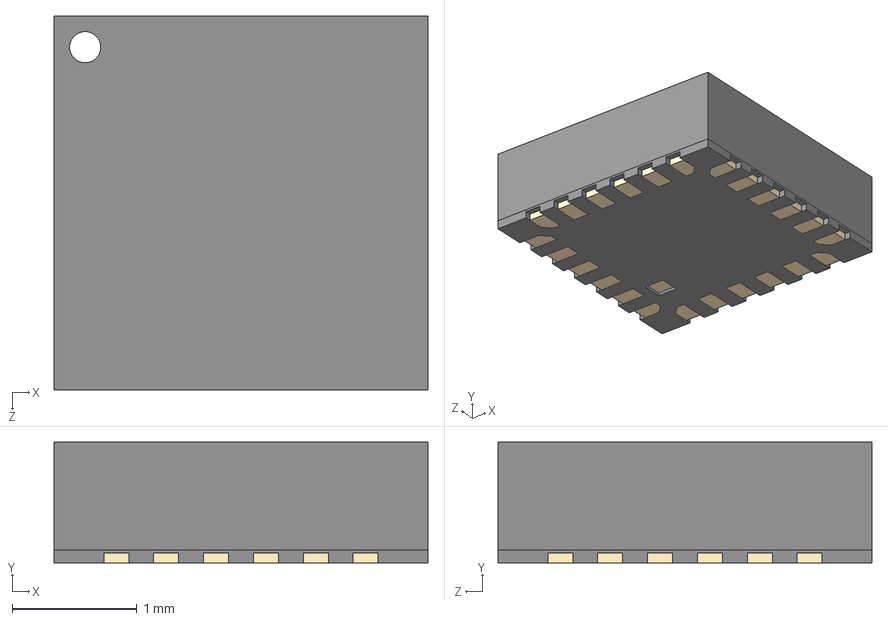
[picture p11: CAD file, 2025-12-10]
hardware/cad-layout/ICM-40609-D/ICM-40609-D.STEP
3.00 x 0.97 x 3.00 mm

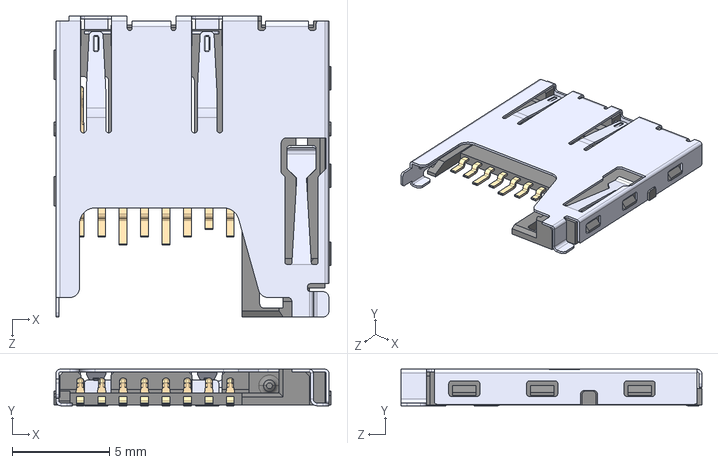
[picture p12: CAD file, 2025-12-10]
hardware/cad-layout/MEM2061/MEM2061-01-188-00-A.STEP
14.2 x 1.88 x 15.4 mm

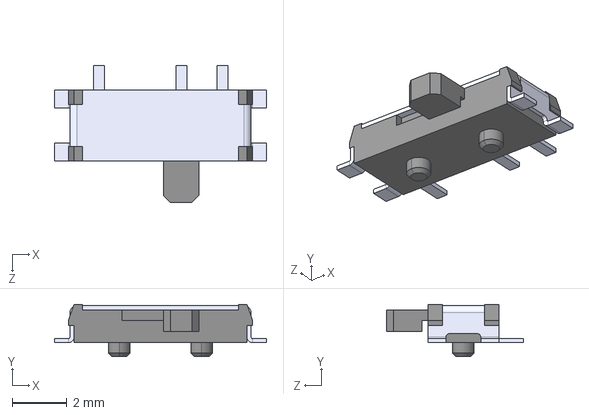
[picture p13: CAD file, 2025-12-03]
hardware/cad-layout/PCM12SMTR/PCM12SMTR.step
7.72 x 1.91 x 4.98 mm

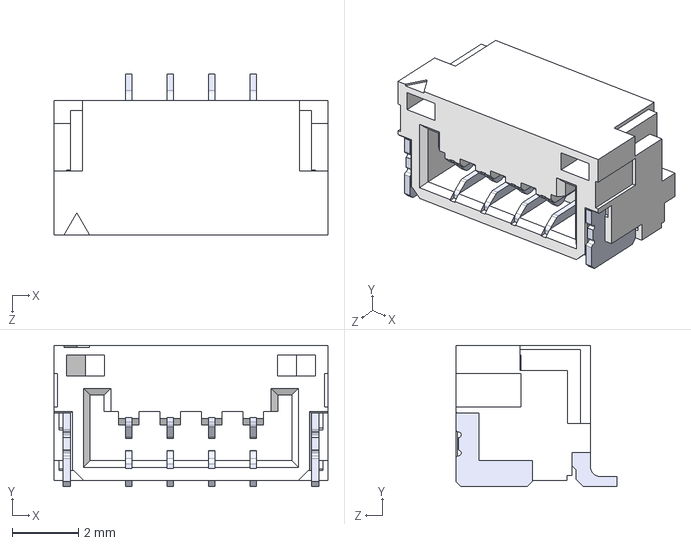
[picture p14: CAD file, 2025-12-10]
hardware/cad-layout/SM04B-GHS-TB/SM04B-GHS-TB.STEP
8.25 x 4.25 x 4.85 mm
SMxB-GHS-TB_04
pin x 4

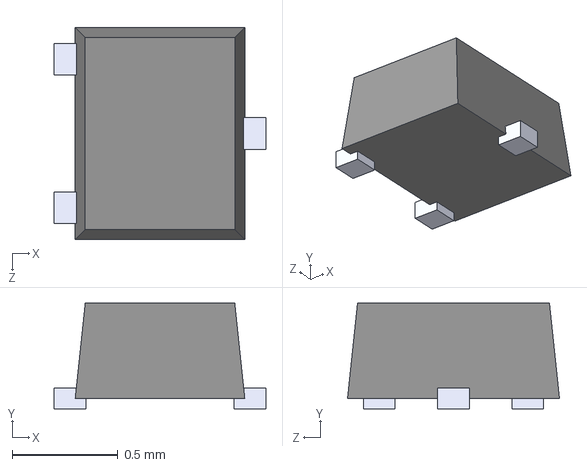
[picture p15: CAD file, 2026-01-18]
hardware/cad-layout/TPD2EUSB30A/TPD2EUSB30ADRTR.step
1.00 x 0.5 x 1.00 mm

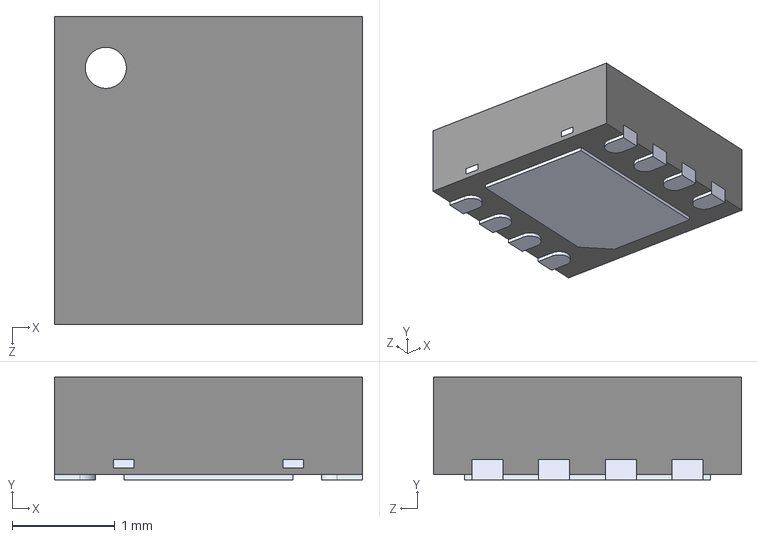
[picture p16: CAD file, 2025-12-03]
hardware/cad-layout/TPS7A2133/TPS7A2133PQWDRBRQ1.step
3.00 x 1.00 x 3.00 mm

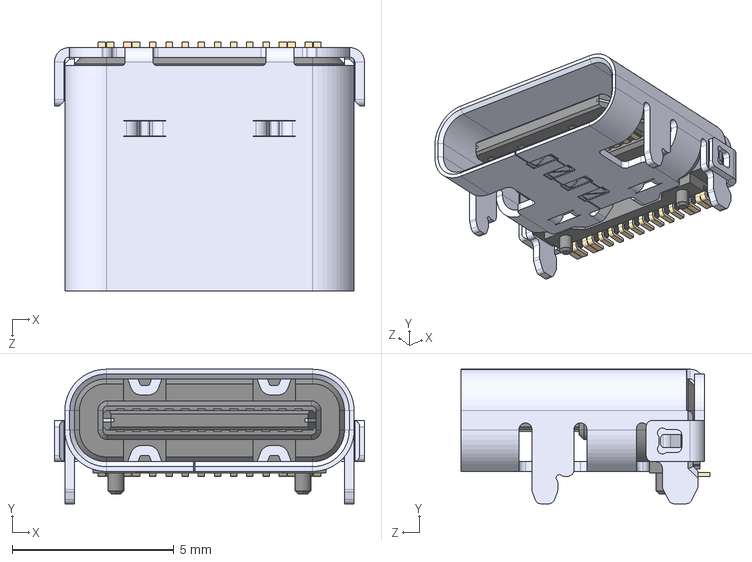
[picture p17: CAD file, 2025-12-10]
hardware/cad-layout/USB4105/USB4105-GF-A.step
9.58 x 4.16 x 7.71 mm

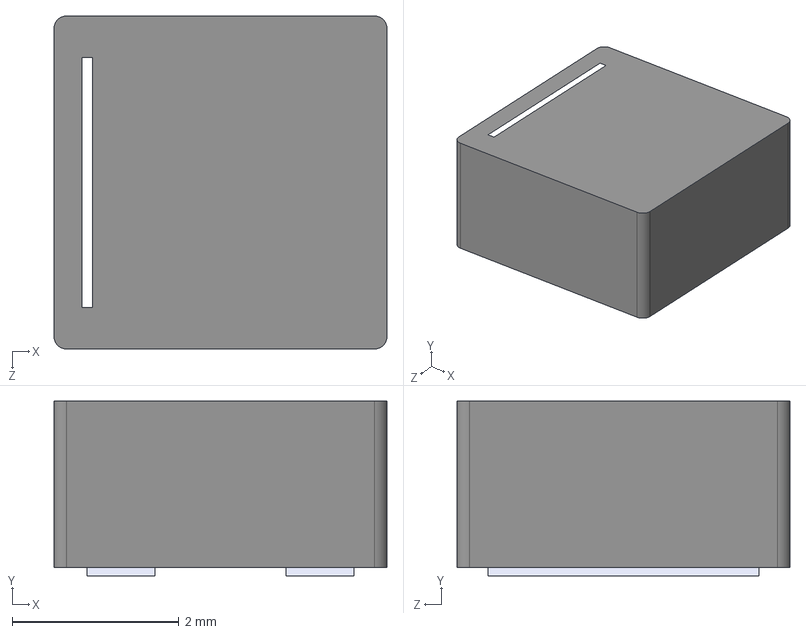
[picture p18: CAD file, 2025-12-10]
hardware/cad-layout/XFL4020-222MEC/XFL4020-222MEC--3DModel-STEP-269445.STEP
4.00 x 2.10 x 4.00 mm

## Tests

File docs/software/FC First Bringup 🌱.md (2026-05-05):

# FC First Bringup 🌱

Here are the steps done to progressively bringup and check the features and components of the Shirley FC:

1. [[#Power stages check]]
2. [[#STM32 power up]]
3. [[#Debug interface (SWD)]]
4. [[#Flash blink program]]

## Power stages check

Check that all voltages are nominal before soldering the jumper resistors that connects the other components

## STM32 power up

Solder the required components for a first STM32 bringup:
- jumper resistors
- BOOT0 slide switch

Check of the voltages are still nominal and stable

## Debug interface (SWD)

- Connect the debug interface (JLink) to the board
- Power the board
- connect the interface to the host PC

Thanks to the debug interface we can then check if the MCU is alive and his basic features work properly. See [Guide on the JLink instructions]([Doc/JLink Cheatsheet ⛓️](obsidian://open?vault=FC-soft-toolkit&file=Doc%2FJLink%20Cheatsheet%20%E2%9B%93%EF%B8%8F))

## Flash blink program 

The next step is to check if we can flash a basic program onto the STM32. We use STM32CubreIDE/STM32CuberMX as it is the easiest/most reliable way to do so.

We configure the LedSys pin output on CubeMX and write a simple led blinking program:
`STM32CubeIDE/LedBlinkTest`
### 1. Internal clock (HSI)

We configure the clock with the HSI at 64Mhz and the prescalers set to 1.
[See STM32 Clock settings](Doc/STM32 Settings ⚙️)
### 2. External Crystal (HSE)

We enable HSE (16MHz) and put it trough PLLCLK to get 80MHz as the CPU clock. 
This allows us to check the External crystal is working properly.

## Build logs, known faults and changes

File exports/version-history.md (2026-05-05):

# Version History

This file present the different versions of the board that have been designed. It also reports wich version has been manufactured and tested

## Current version information:

FC manufactured

- name : ***Shirley***
- descriptive name : **FC Dev Board**
- version number: **0.9.5**
- *[Schematic not exported]*
- Manufactured : produced 
- Tested : ***In testing...***
    - ✅ Elec checks
    - ✅ STM32 checks
    - 🔄 Sensors

## Past versions:
- v0.9:
Note: changed the barometer to BMP388 (stock issue)
- v0.8:
Note: changed the USB-C ESD protection
- v0.7:
[Schematic exported](FC-Dev-Board-v0.7-Schem.pdf)
; Note: Design posted and reviewed([reddit](https://www.reddit.com/r/PrintedCircuitBoard/comments/1qci8jg/review_request_drone_flight_controller_with/))
- v0.5:
[Schematic exported](past-versions/FC_Schem_v0.5.pdf)
- v0.3:
[Schematic exported](past-versions/FC_Schem_v0.3.pdf)
; Note : Use the ICM-42688-P IMU

---

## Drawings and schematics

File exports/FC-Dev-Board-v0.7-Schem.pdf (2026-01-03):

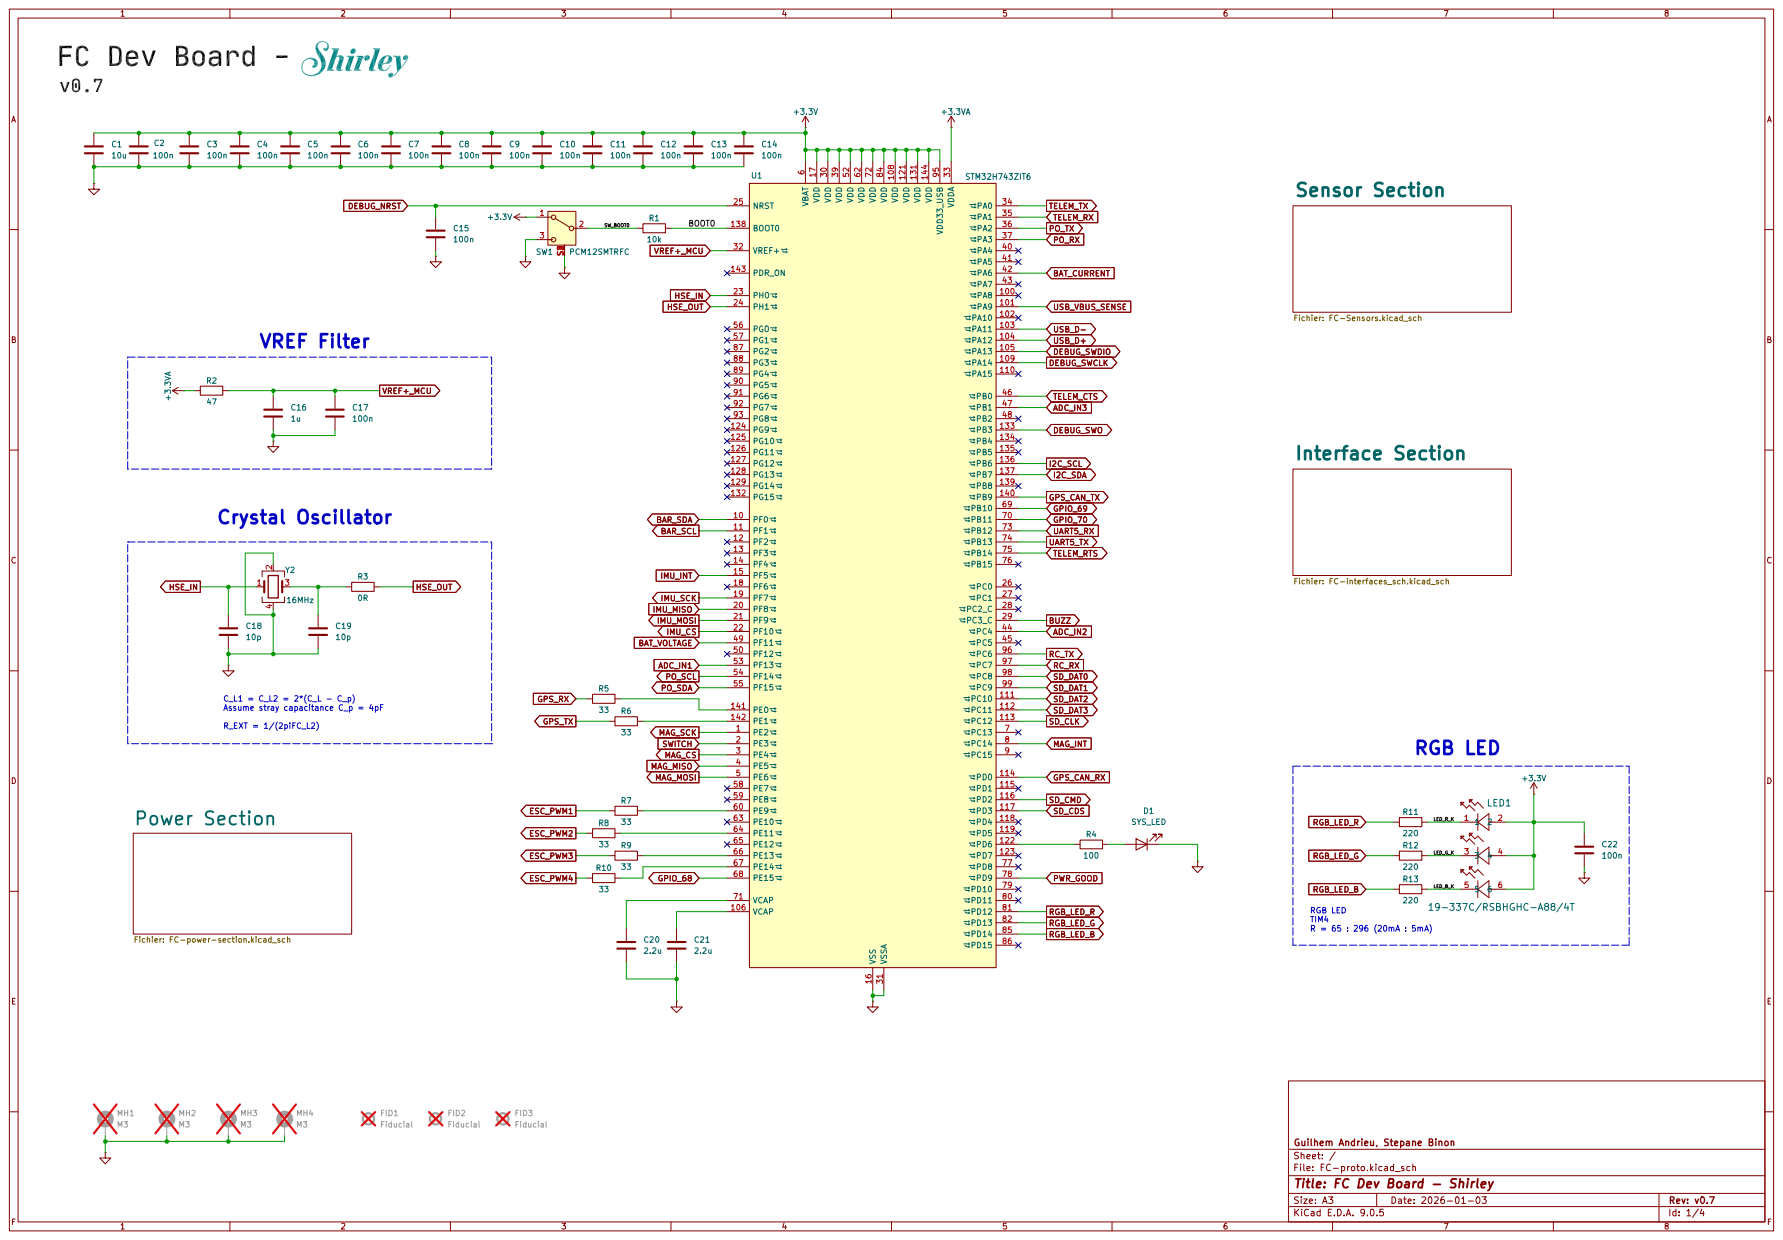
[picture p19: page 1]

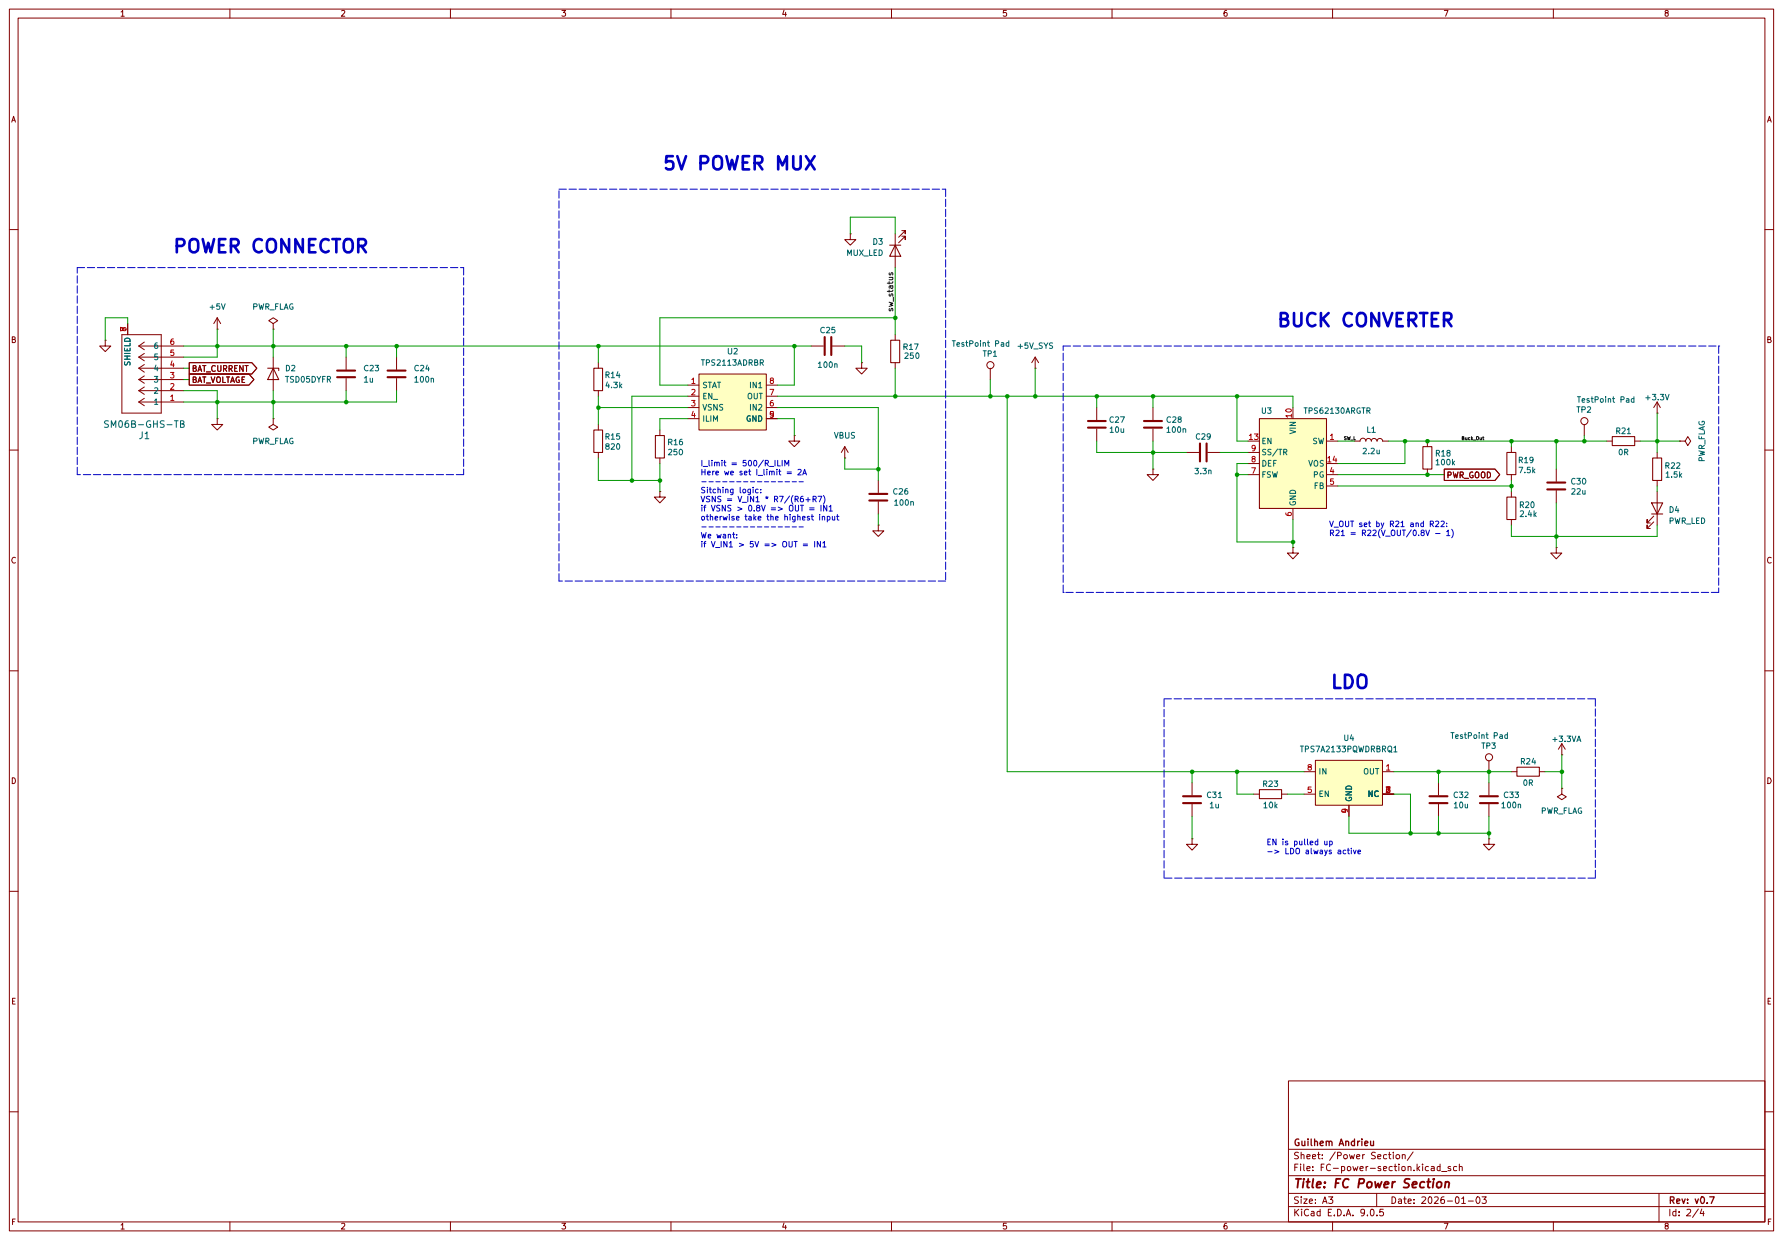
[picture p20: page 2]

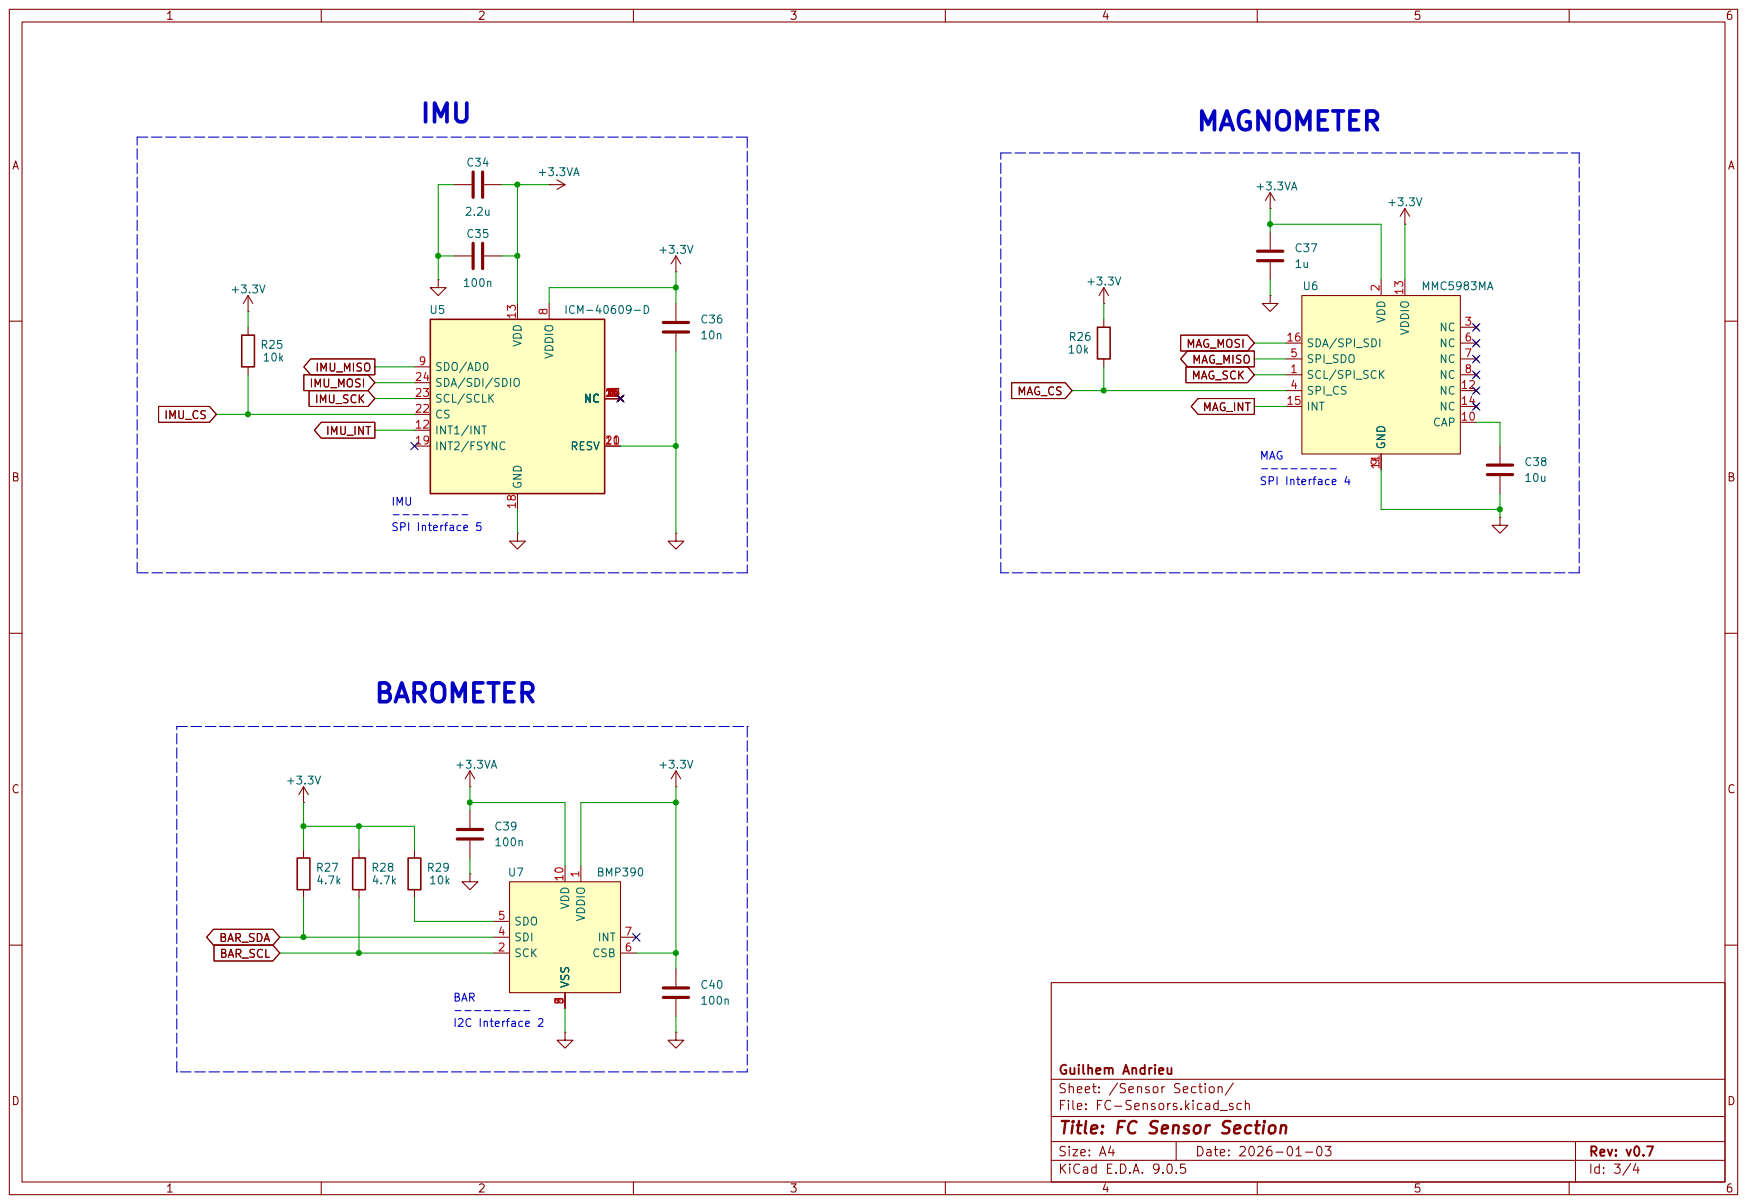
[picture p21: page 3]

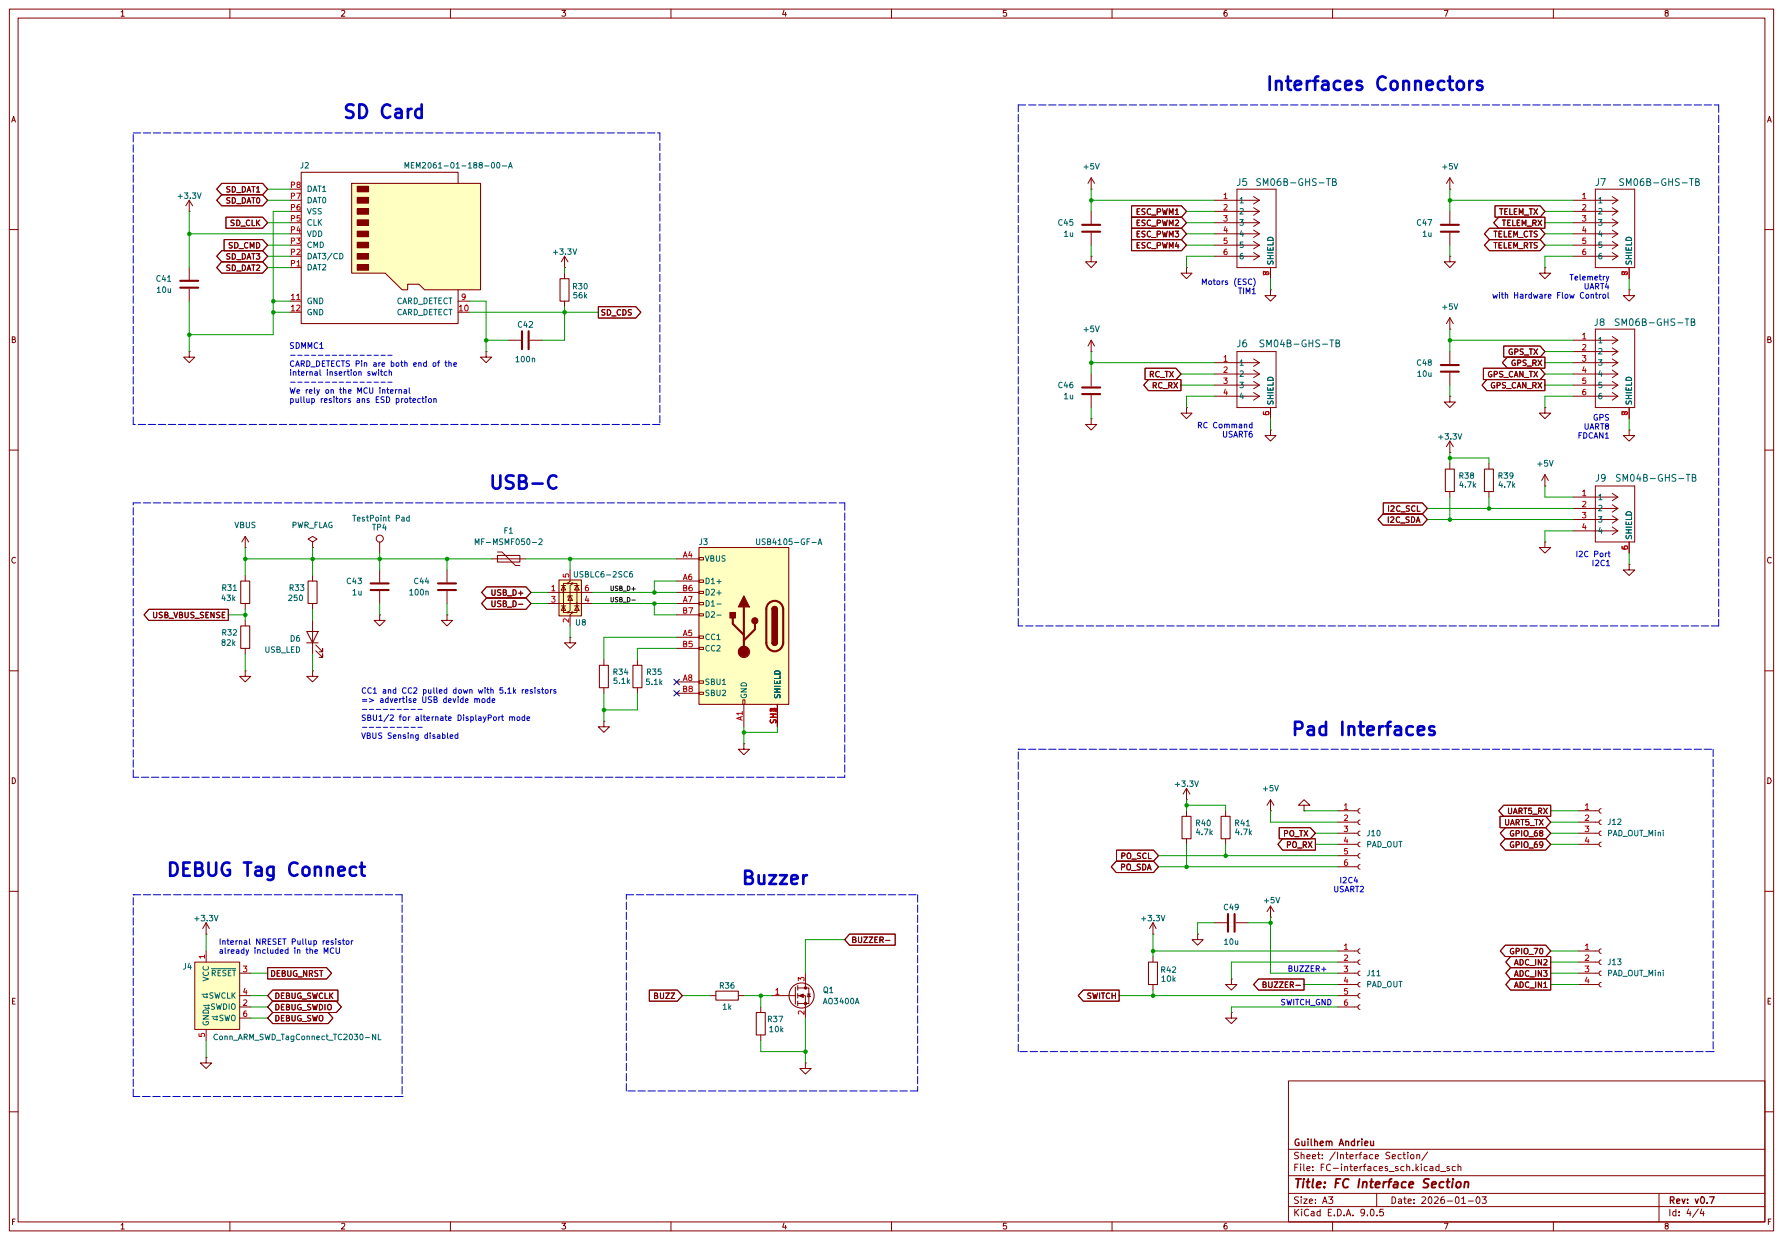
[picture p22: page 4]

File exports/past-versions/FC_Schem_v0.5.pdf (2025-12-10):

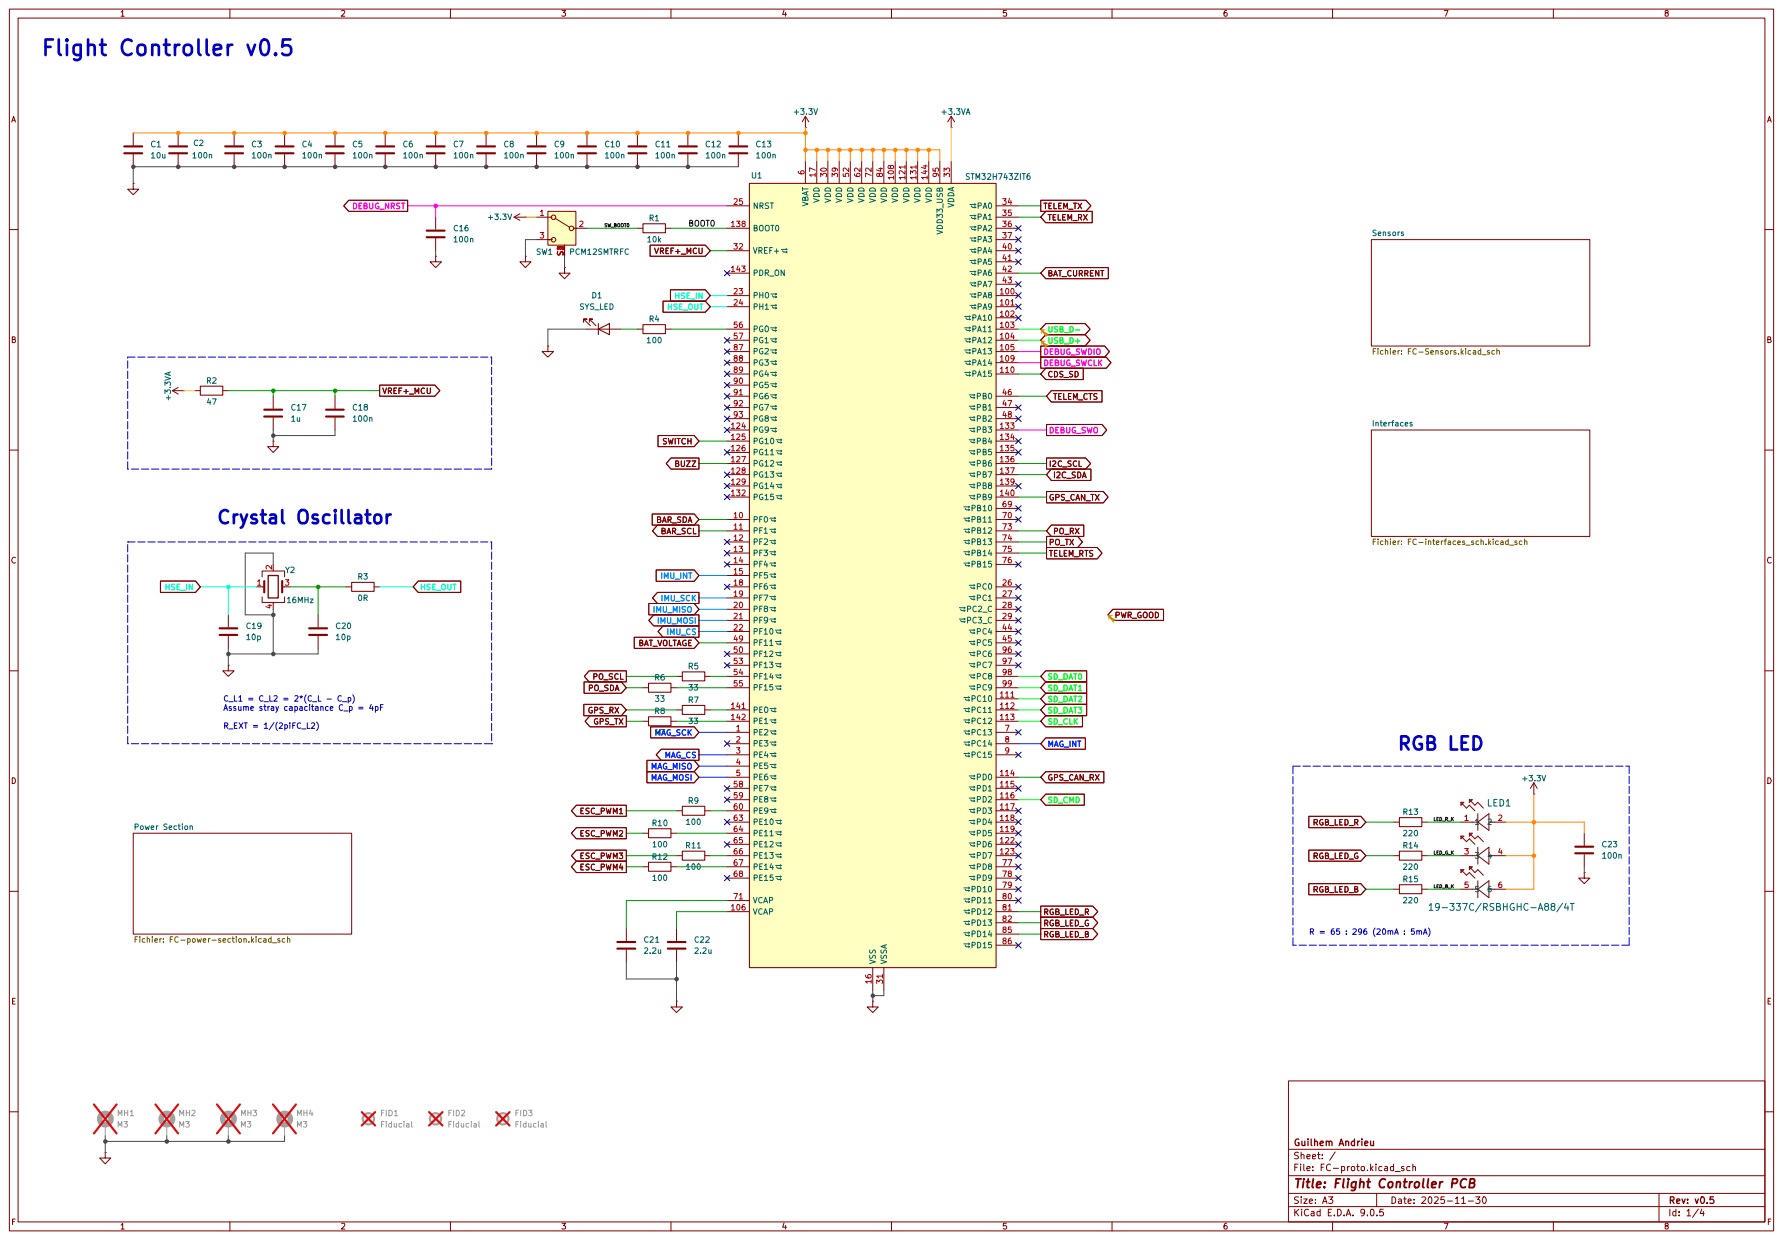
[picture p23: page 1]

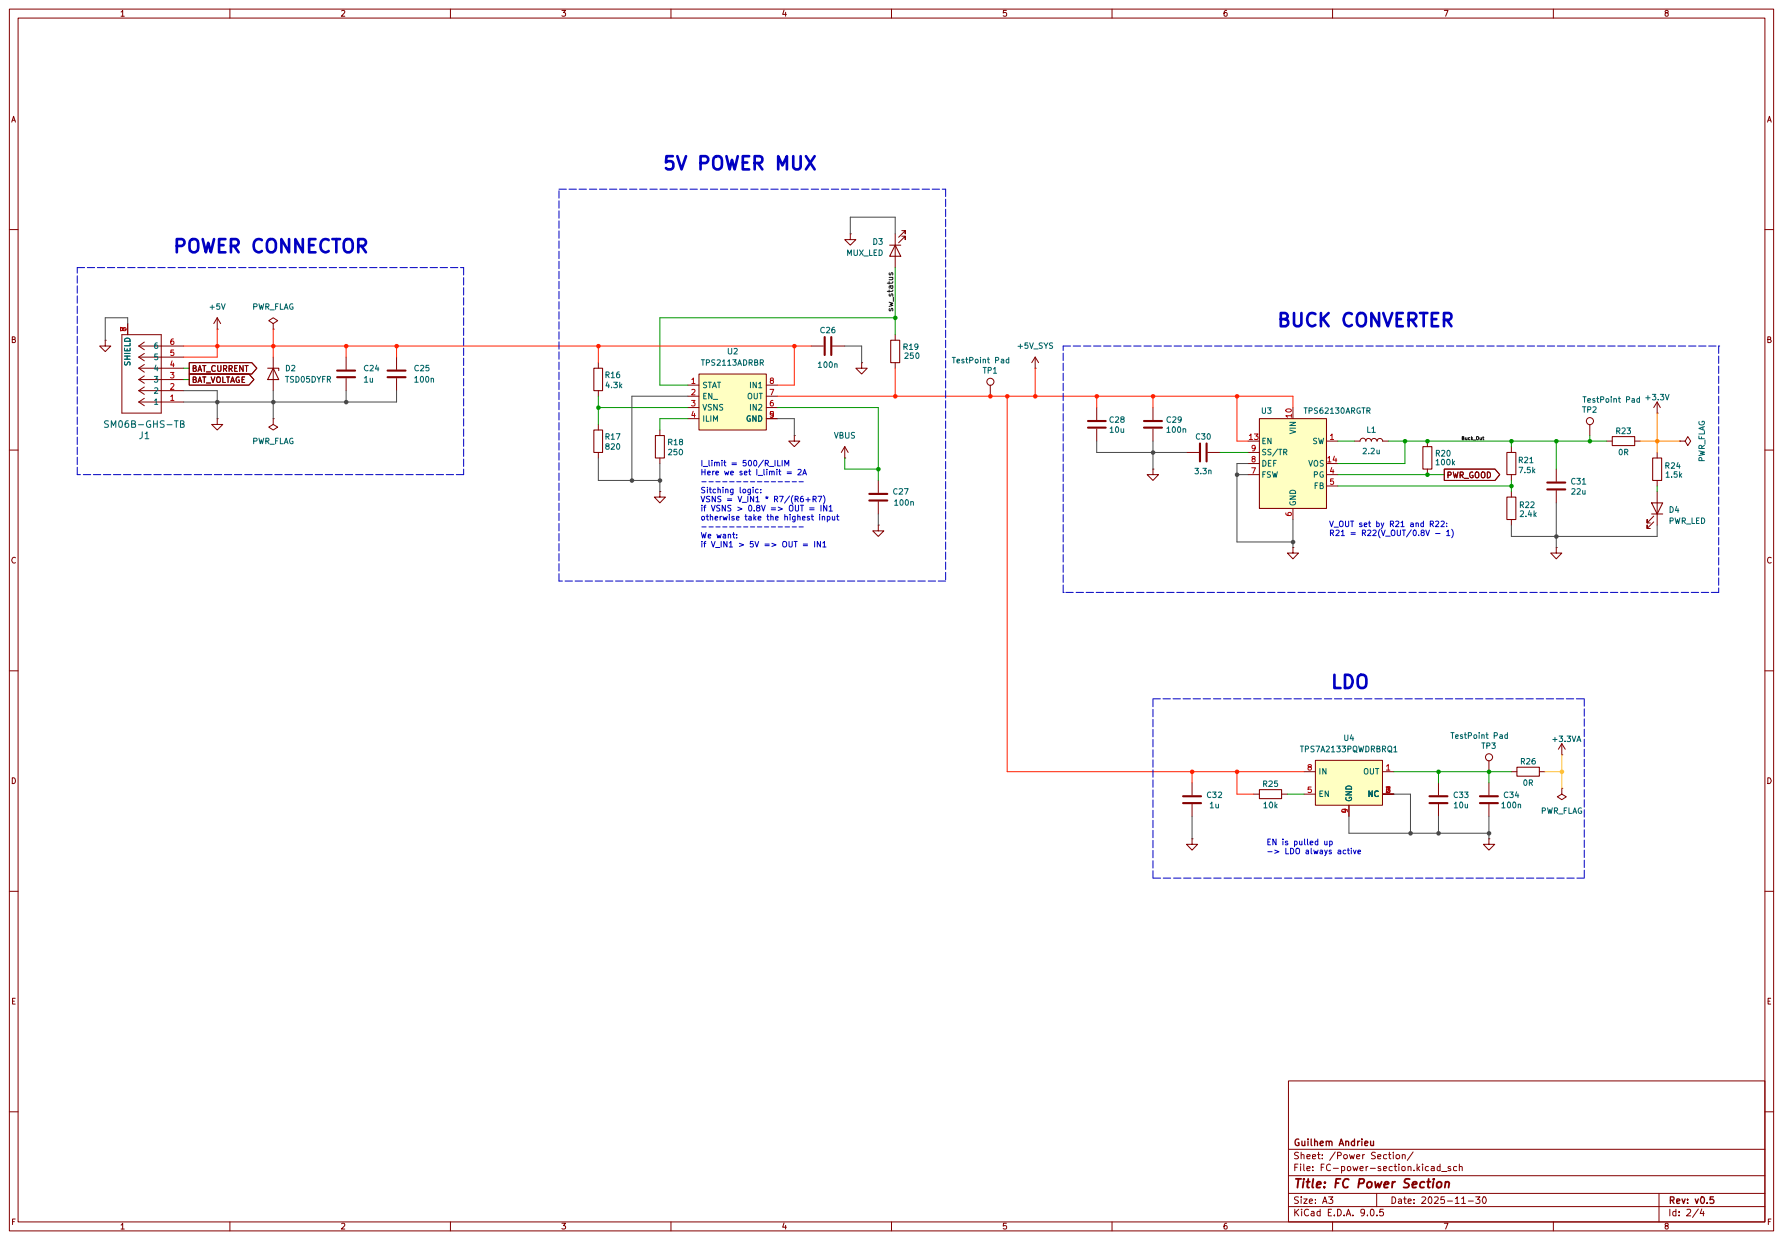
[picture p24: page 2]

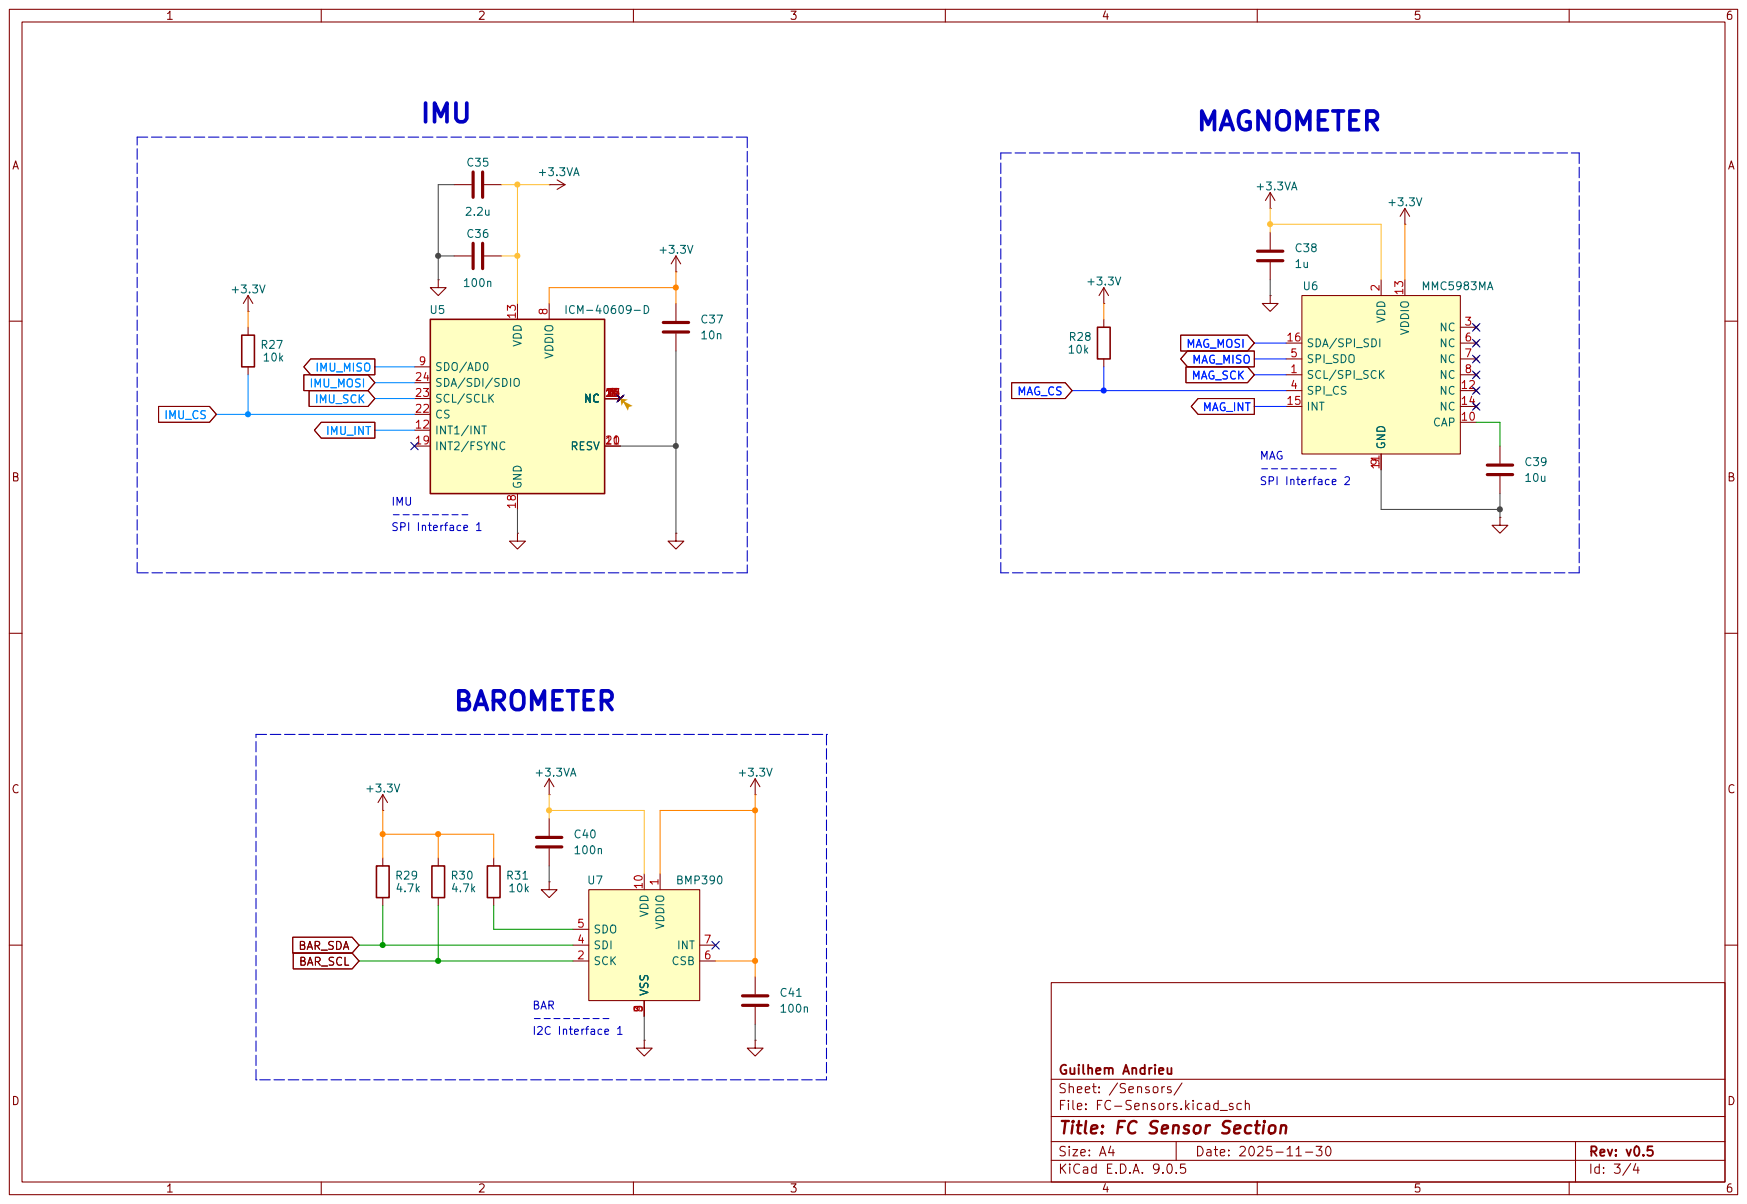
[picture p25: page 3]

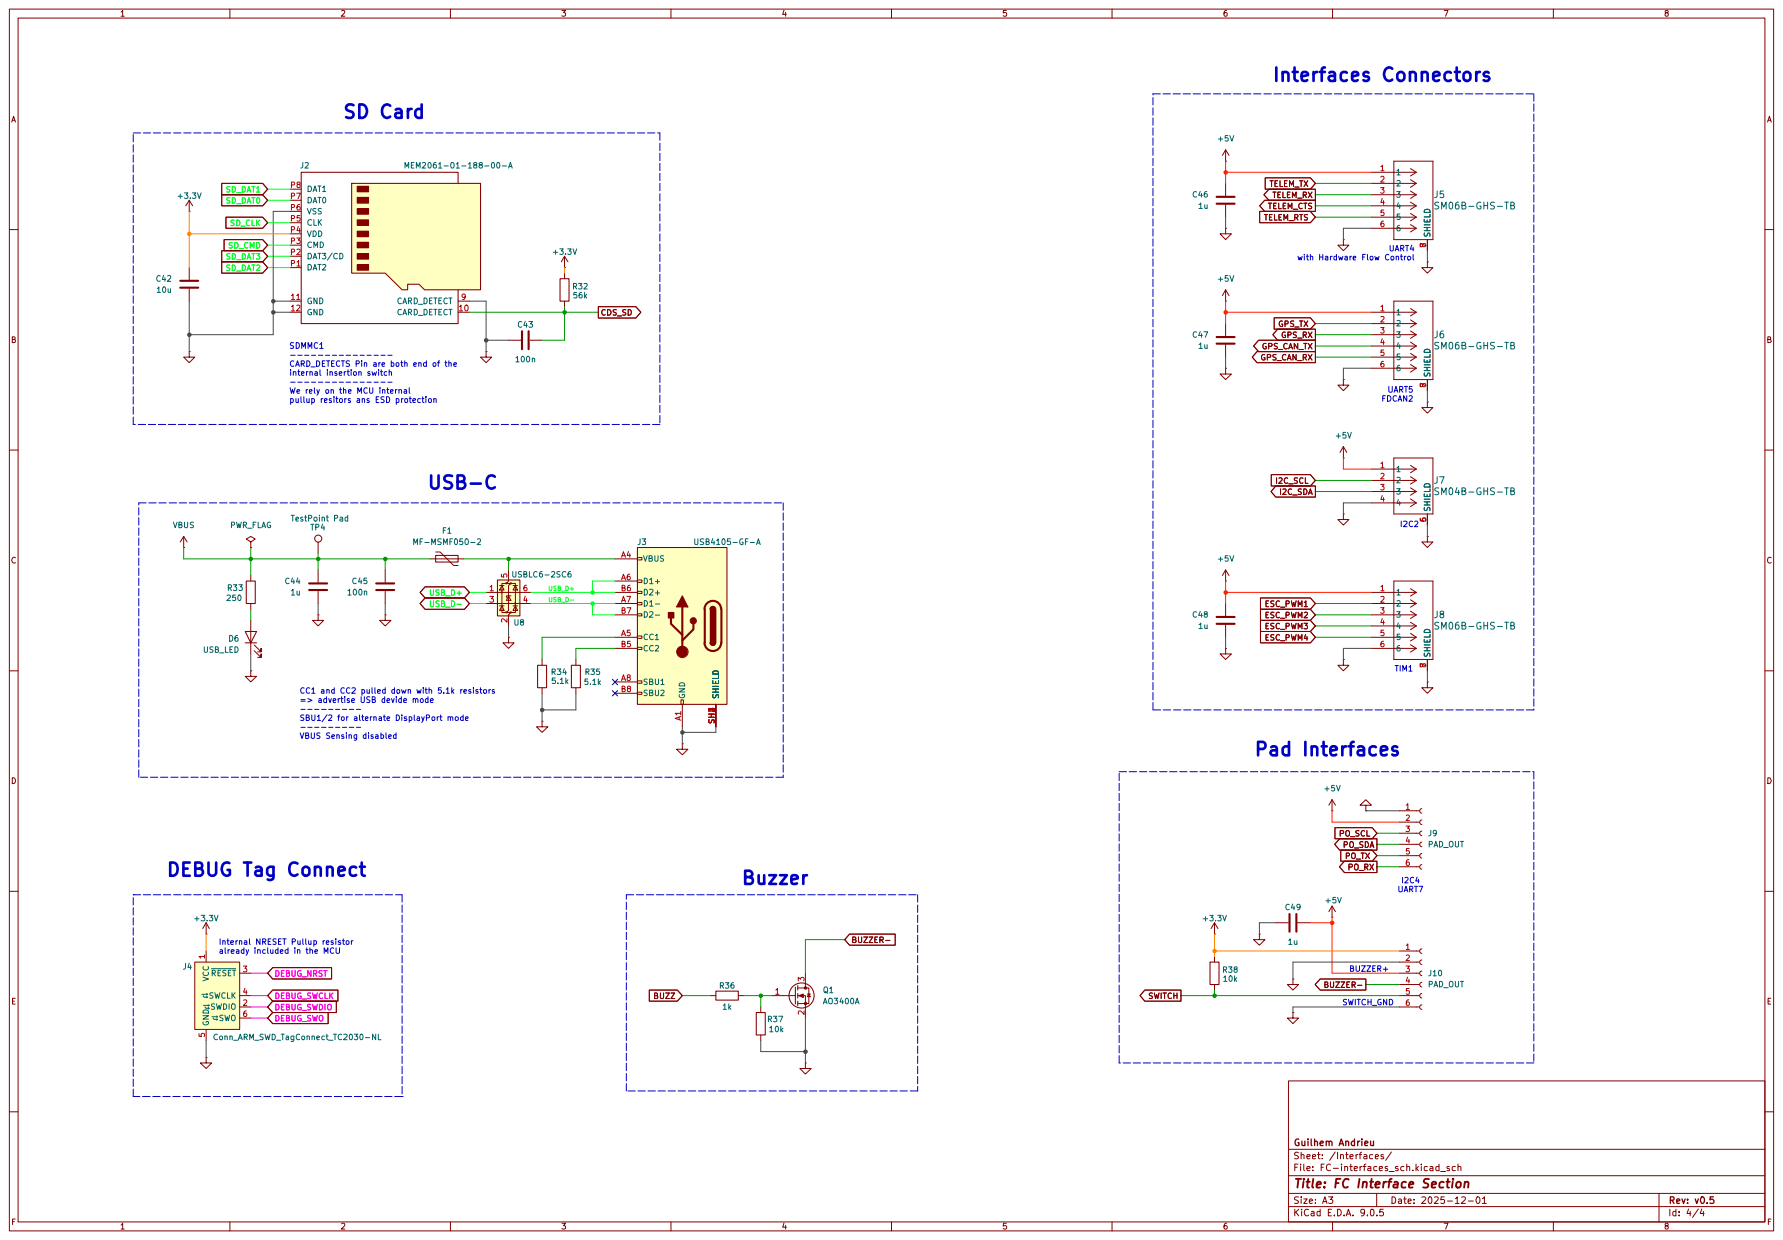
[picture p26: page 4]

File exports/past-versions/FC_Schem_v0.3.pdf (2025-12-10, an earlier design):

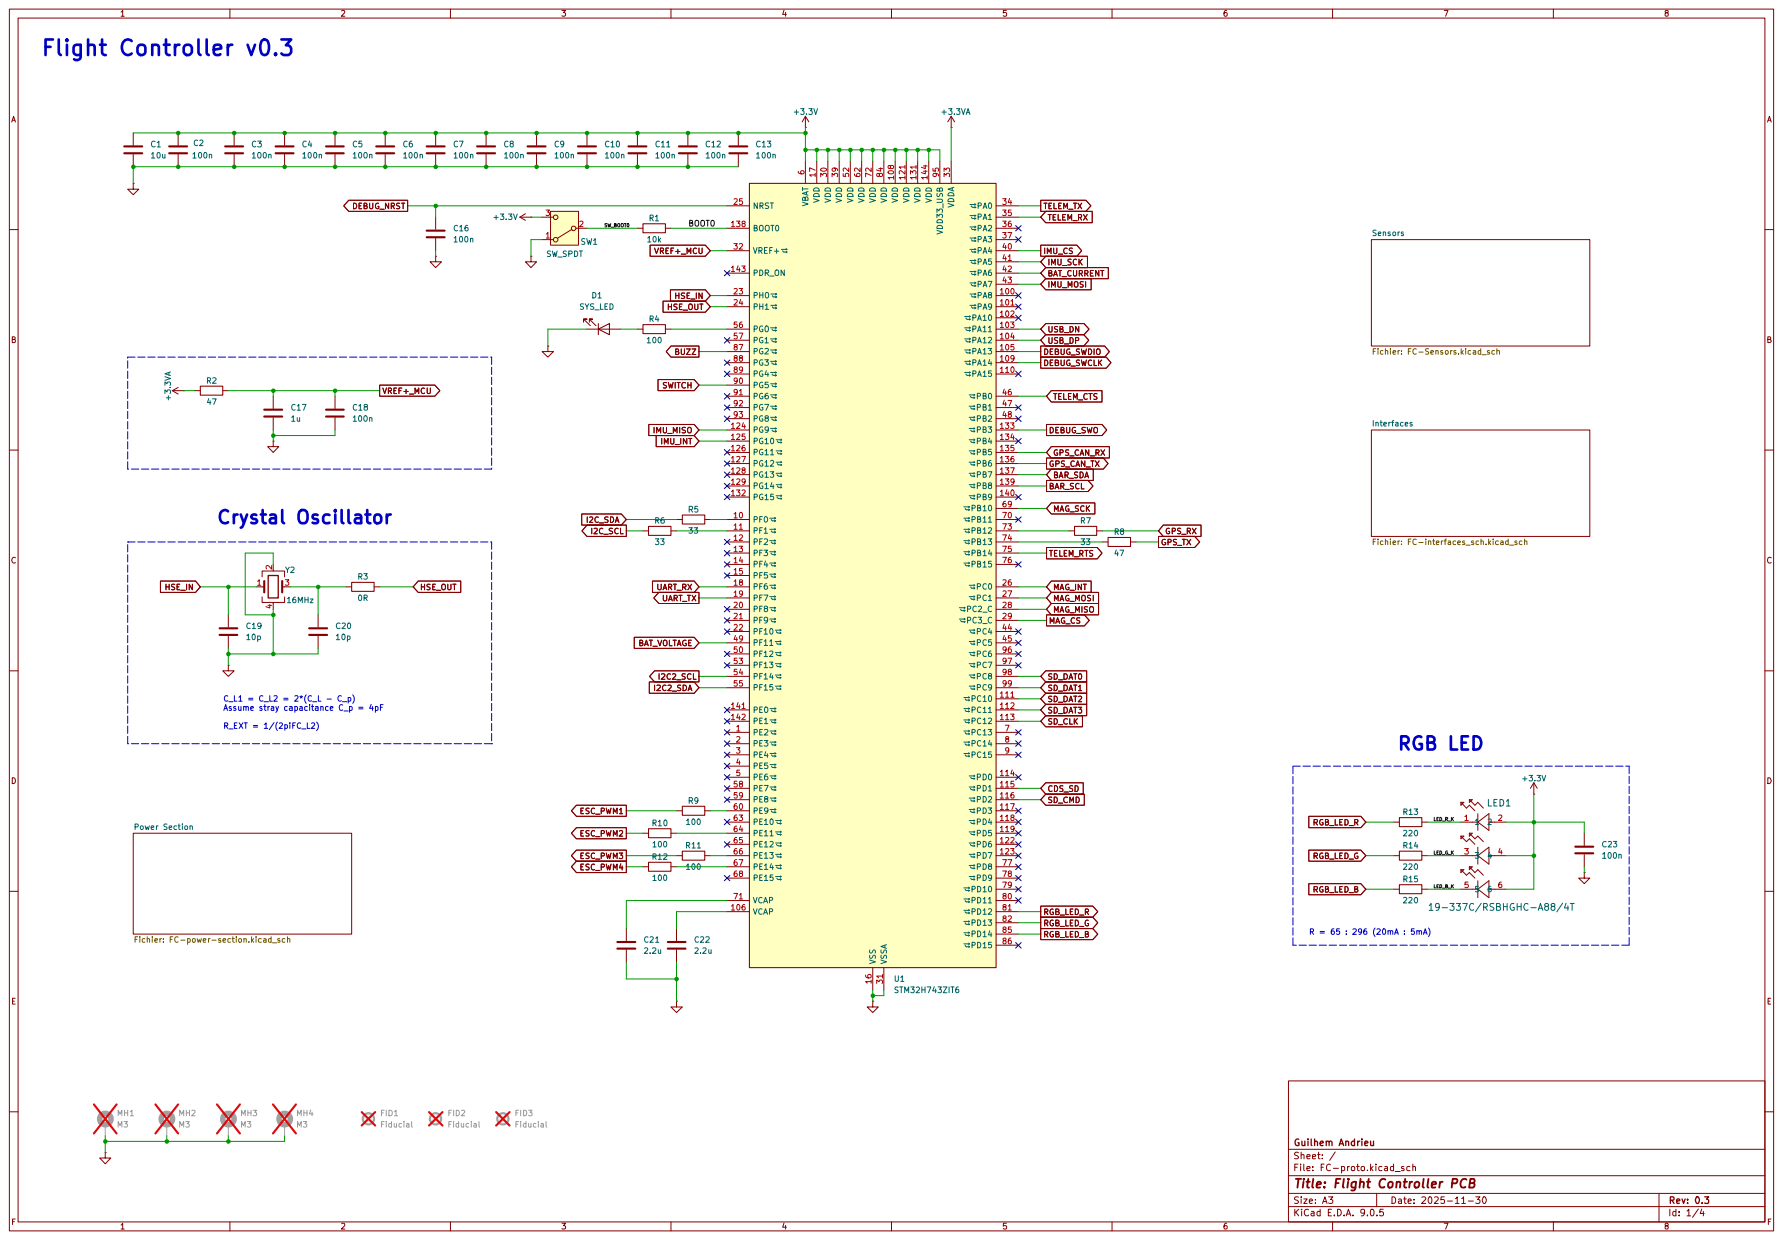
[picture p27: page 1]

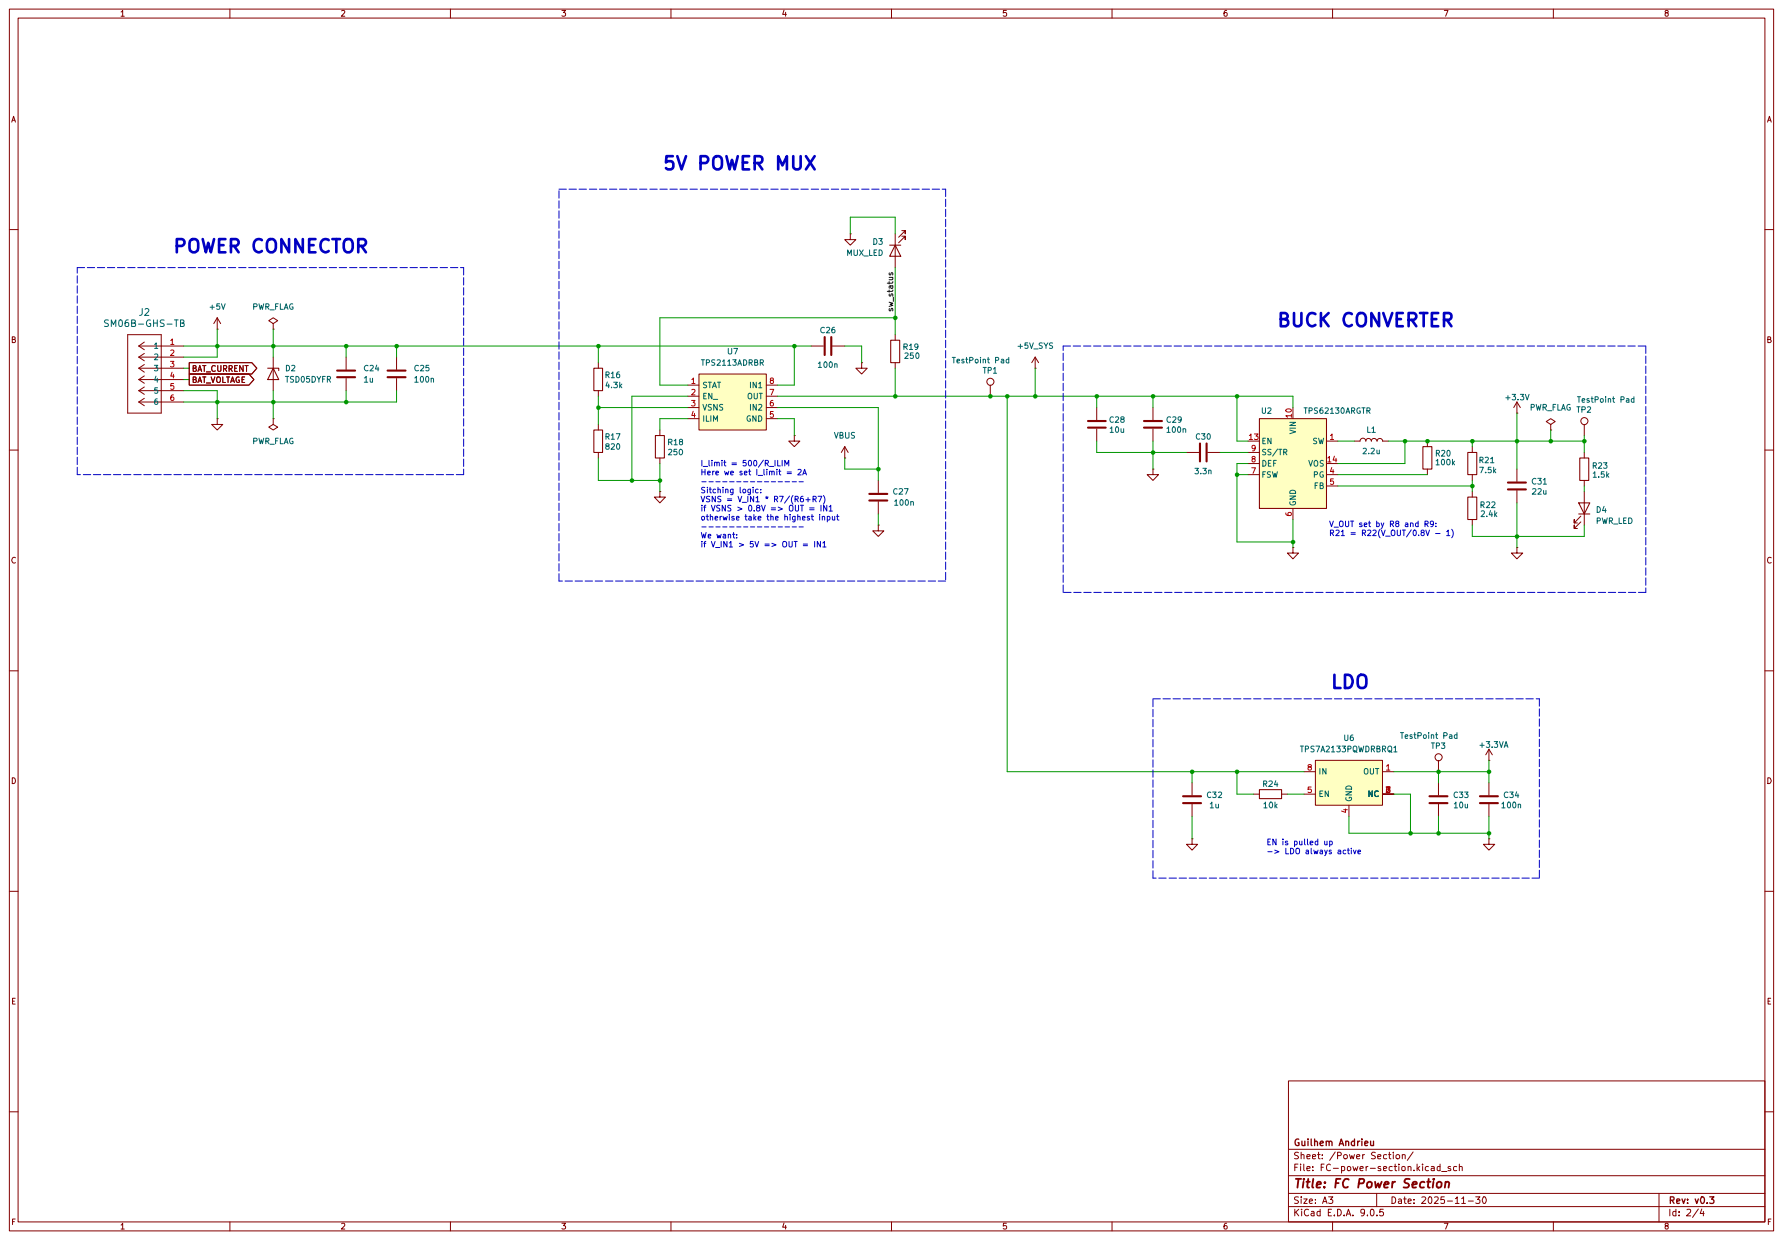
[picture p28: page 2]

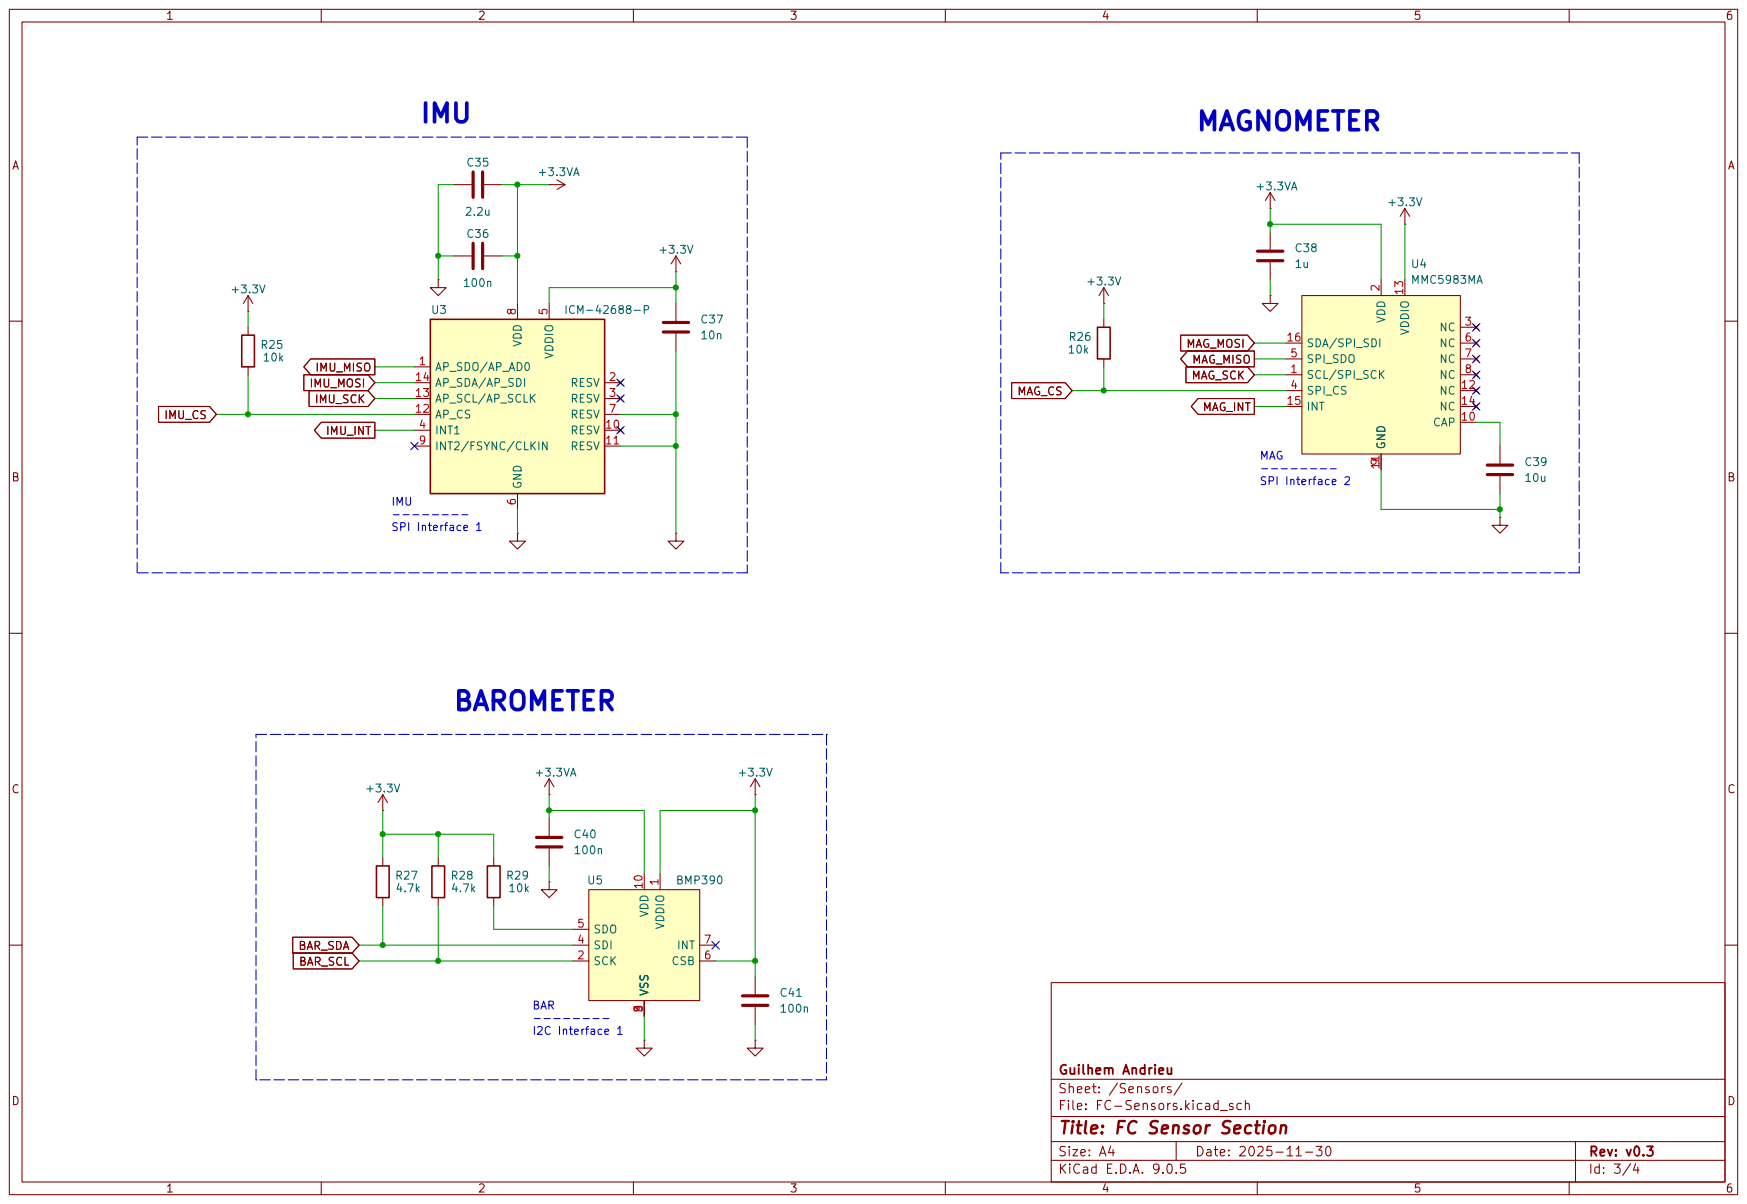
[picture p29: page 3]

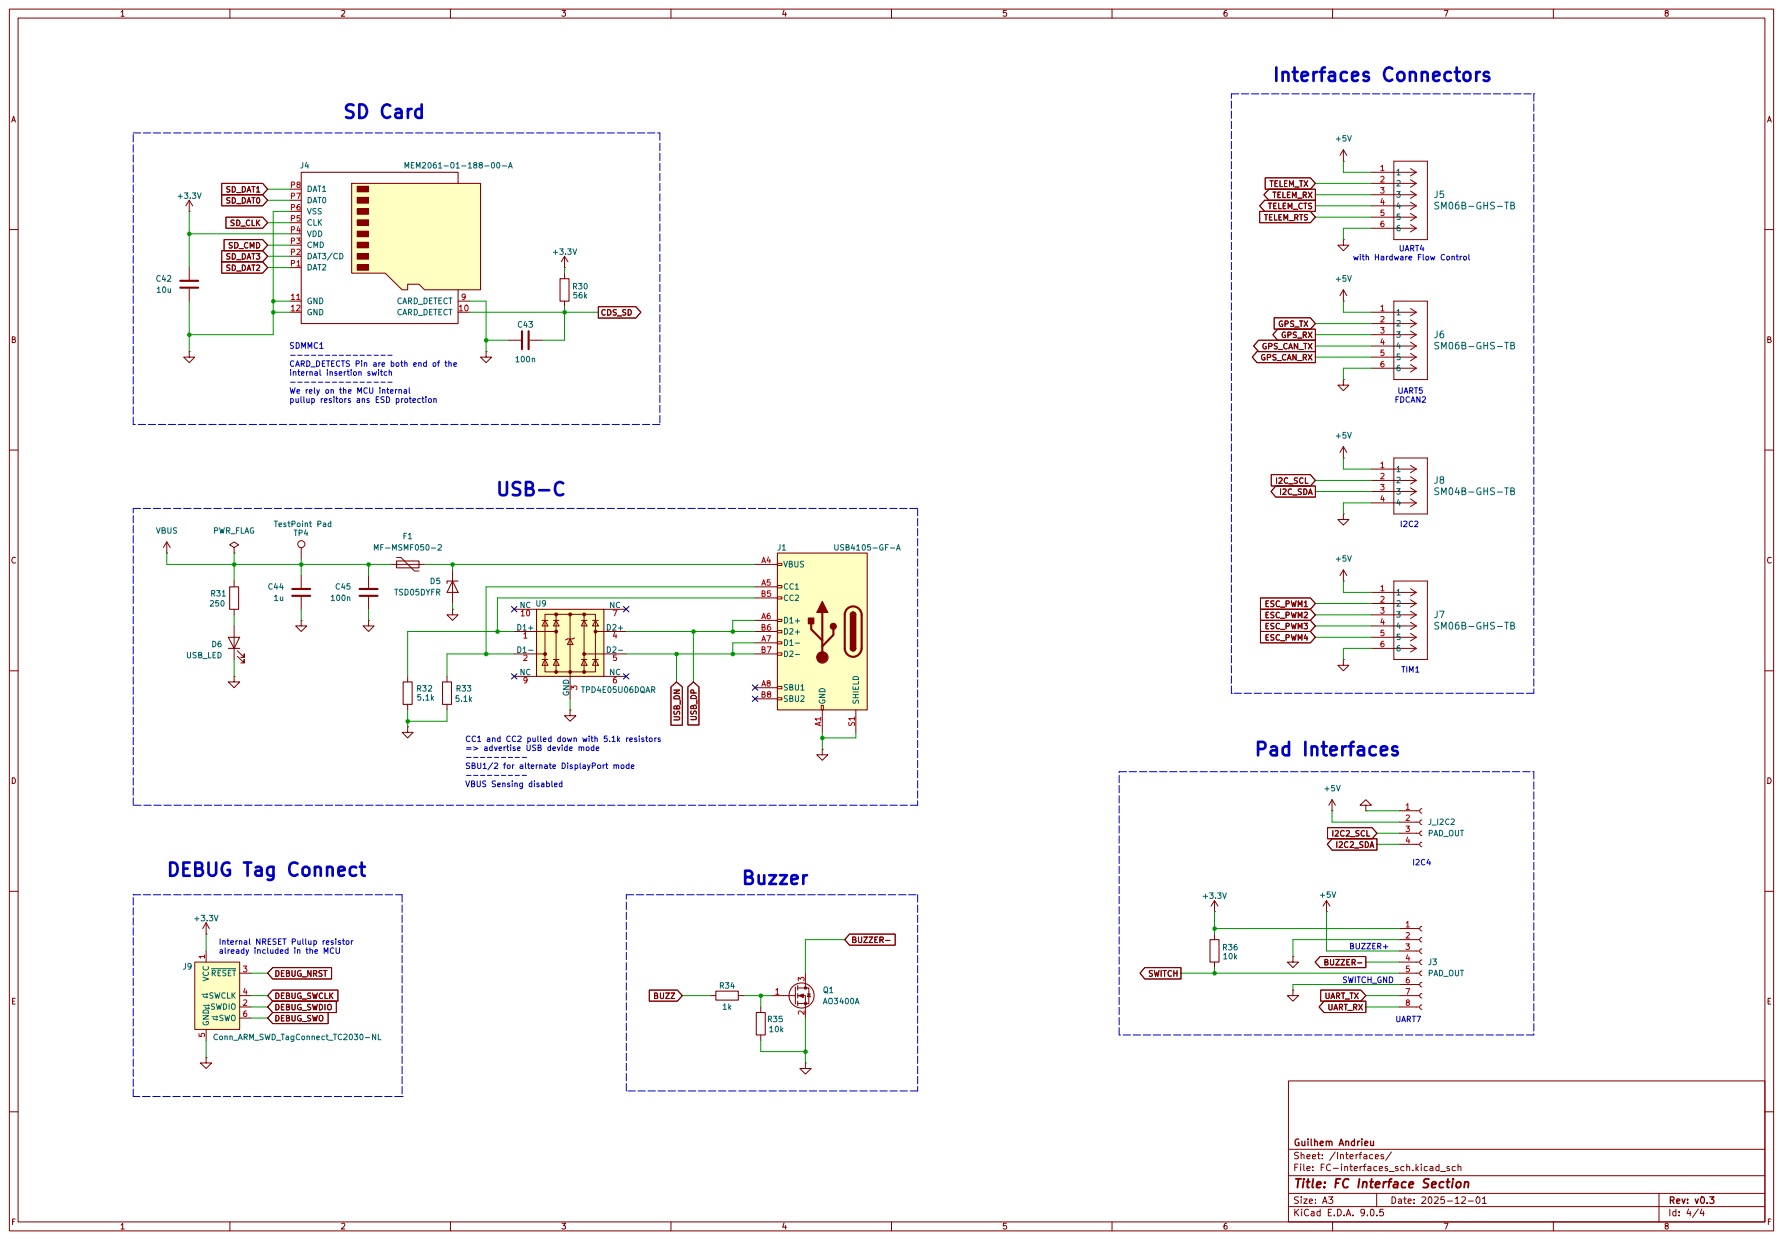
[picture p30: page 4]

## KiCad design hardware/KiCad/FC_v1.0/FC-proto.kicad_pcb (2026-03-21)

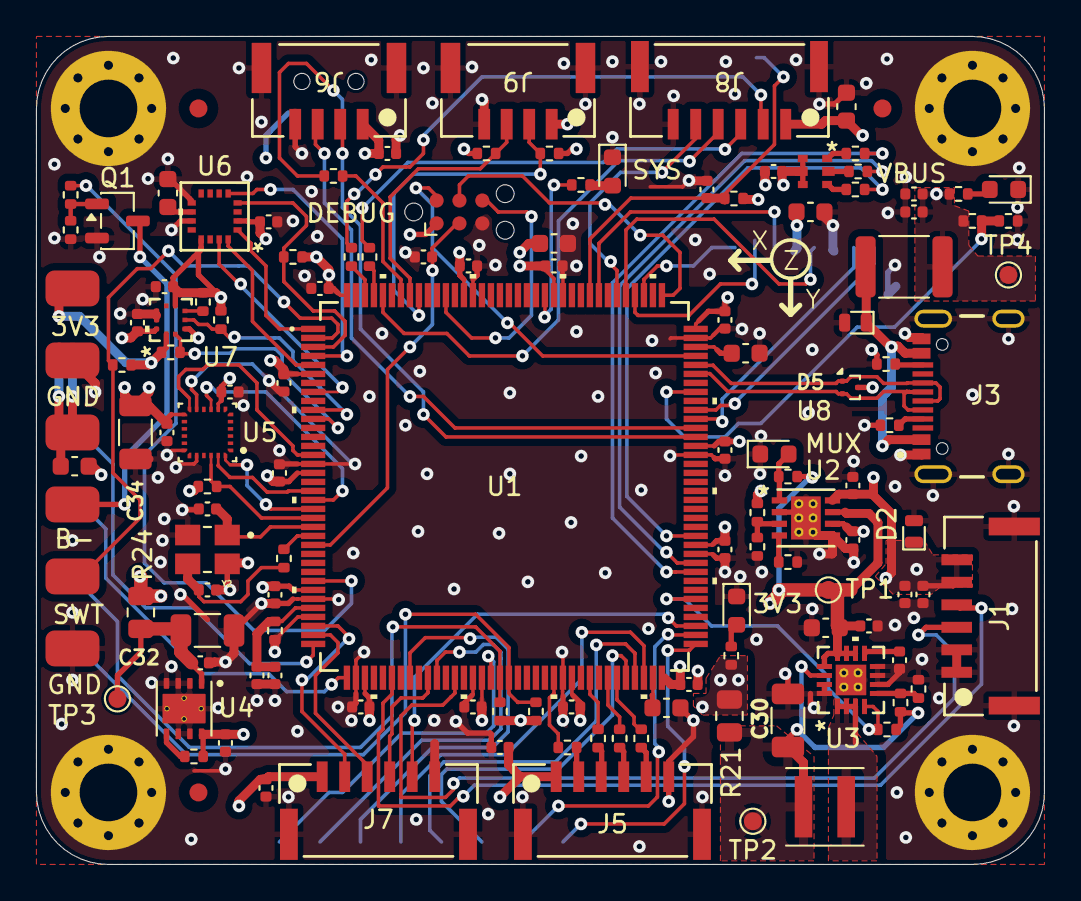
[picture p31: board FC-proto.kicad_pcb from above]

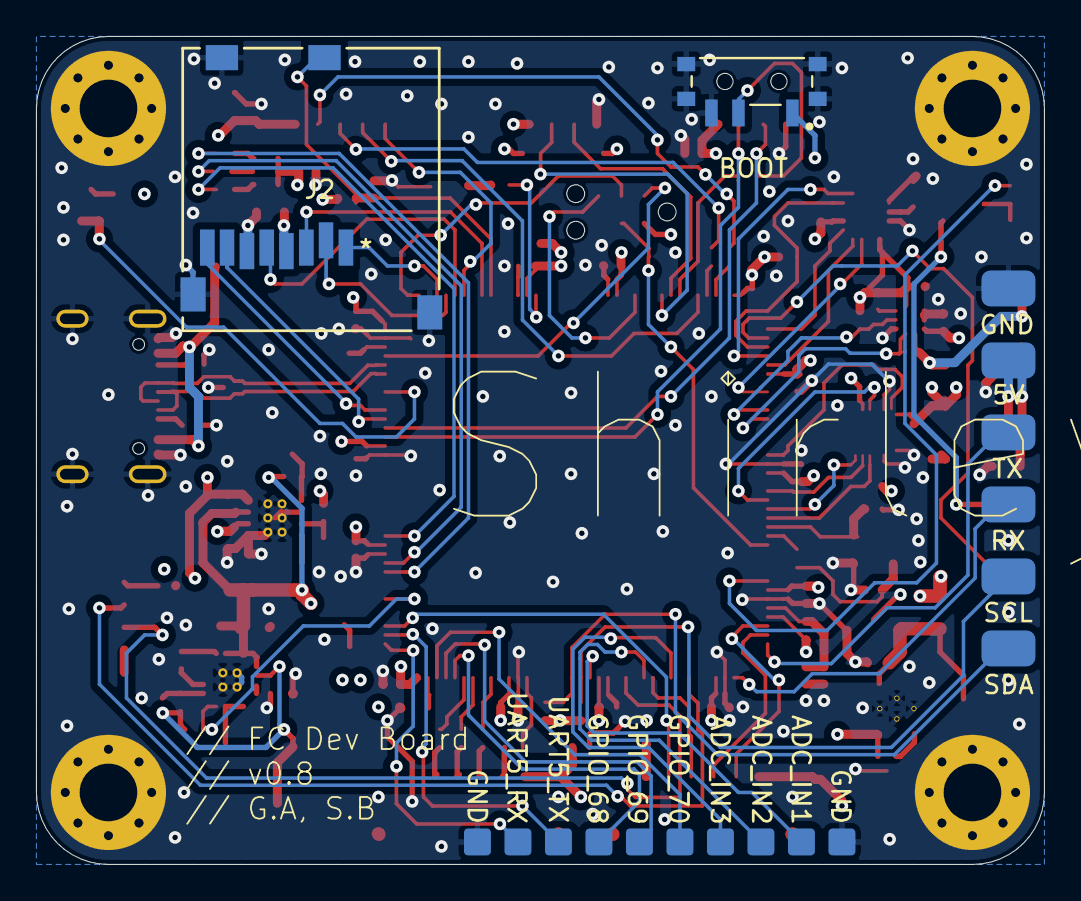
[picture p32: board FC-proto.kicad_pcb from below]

Board: 4 copper layers, 56.0 x 46.0 mm, 135 parts (5 on the bottom side), 105 nets.

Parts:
C1, C27, C38, C41, C48, C49: 10u; C_0603_1608Metric
C2, C3, C4, C5, C6, C7, C8, C9, C10, C11, C12, C13, C14, C15, C17, C22, C24, C25, C26, C28, C33, C35, C39, C40, C42, C44: 100n; C_0402_1005Metric
C16, C23, C31, C37, C43, C45, C46, C47: 1u; C_0402_1005Metric
C18, C19: 10p; C_0402_1005Metric
C20, C21: 2.2u; C_0603_1608Metric
C29: 3.3n; C_0402_1005Metric
C30: 22u; C_1206_3216Metric
C32: 10u; C_1206_3216Metric
C34: 2.2u; C_1206_3216Metric
C36: 10n; C_0402_1005Metric
D1: SYS_LED; LED_0603_1608Metric
D2, D5: LTVS16H5; DFN1610-2
D3: MUX_LED; LED_0603_1608Metric
D4: PWR_LED; LED_0603_1608Metric
D6: USB_LED; LED_0603_1608Metric
F1: MF-MSMF050-2; Fuse_1812_4532Metric
FID1, FID2, FID3: Fiducial; Fiducial_1mm_Mask2mm
J1, J5, J7, J8: SM06B-GHS-TB; CONN_SM06B-GHS-TB_JST
J2: MEM2061-01-188-00-A; MEM2061-01-188-00-A_GCT
J3: USB4105-GF-A; GCT_USB4105-GF-A
J4: Conn_ARM_SWD_TagConnect_TC2030-NL; Tag-Connect_TC2030-IDC-NL_2x03_P1.27mm_Vertical
J6, J9: SM04B-GHS-TB; CONN_SM04B-GHS-TB_JST
J10, J11: PAD_OUT; Pad_out_1x6
J12, J13: Conn_01x05; Pad_out_mini_1x5
L1: 2.2u; L_Coilcraft_XxL4020
LED1: 19-337C/RSBHGHC-A88/4T; SMD-B_19-337C_EVE
MH1, MH2, MH3, MH4: M3; MountingHole_3.2mm_M3_Pad_Via
Q1: AO3400A; SOT-23-3
R1, R23, R25, R26, R29, R37, R42: 10k; R_0402_1005Metric
R2: 47; R_0402_1005Metric
R3: 0R; R_0402_1005Metric
R4: 100; R_0402_1005Metric
R5, R6, R7, R8, R9, R10: 33; R_0402_1005Metric
R11, R12, R13: 220; R_0402_1005Metric
R14: 4.3k; R_0402_1005Metric
R15: 820; R_0402_1005Metric
R16, R17, R33: 250; R_0402_1005Metric
R18: 100k; R_0402_1005Metric
R19: 7.5k; R_0402_1005Metric
R20: 2.4k; R_0402_1005Metric
R21, R24: 0R; R_0805_2012Metric
R22: 1.5k; R_0402_1005Metric
R27, R28: 2.2k; R_0402_1005Metric
R30: 56k; R_0402_1005Metric
R31: 43k; R_0402_1005Metric
R32: 82k; R_0402_1005Metric
R34, R35: 5.1k; R_0402_1005Metric
R36: 1k; R_0402_1005Metric
R38, R39, R40, R41: 4.7k; R_0402_1005Metric
SW1: PCM12SMTRFC; SW_PCM12SMTR
TP1, TP2, TP3, TP4: TestPoint; TestPoint_Pad_D1.0mm
U1: STM32H743ZIT6
U2: TPS2113ADRBR; TPS2113A
U3: TPS62130ARGTR
U4: TPS7A2133PQWDRBRQ1
U5: ICM-40609-D
U6: MMC5983MA
U7: BMP390
U8: TPD2EUSB30A; Texas_DRT-3
Y2: 16MHz; TSX-3225_16MHz

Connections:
+3.3V: C1.1, C2.1, C3.1, C4.1, C5.1, C6.1, C7.1, C8.1, C9.1, C10.1, C11.1, C12.1, C13.1, C14.1, C22.1, C36.1, C40.1, C41.1, J2.P4 (VDD), J4.1 (VCC), J11.1, LED1.2, LED1.4, LED1.6, R21.1, R22.2, R25.2, R26.2, R27.2, R28.2, R29.2, R30.2, R38.2, R39.2, R40.2, R41.2, R42.2, SW1.1 (A), U1.6 (VBAT), U1.17 (VDD), U1.30 (VDD), U1.39 (VDD), U1.52 (VDD), U1.62 (VDD), U1.72 (VDD), U1.84 (VDD), U1.95 (VDD33_USB), U1.108 (VDD), U1.121 (VDD), U1.131 (VDD), U1.144 (VDD), U5.8 (VDDIO), U6.13 (VDDIO), U7.1 (VDDIO), U7.6 (CSB)
+3.3VA: C34.2, C35.2, C37.1, C39.1, R2.1, R24.1, U1.33 (VDDA), U5.13 (VDD), U6.2 (VDD), U7.10 (VDD)
+5V: C23.1, C24.1, C25.1, C45.1, C46.1, C47.1, C48.1, C49.2, D2.1 (K), J1.5, J1.6, J5.1, J6.1, J7.1, J8.1, J9.1, J10.2, J11.3, R14.2, U2.8 (IN1)
+5V_SYS: C27.2, C28.2, C31.2, R17.1, R23.2, TP1.1, U2.7 (OUT), U3.10 (VIN), U3.11 (VIN), U3.12 (VIN), U3.13 (EN), U4.8 (IN)
/BOOT0: R1.2, U1.138 (BOOT0)
/LED_B_K: LED1.5, R13.2
/LED_G_K: LED1.3, R12.2
/LED_R_K: LED1.1, R11.2
/Power Section/Buck_Out: C30.2, L1.2, R18.2, R19.2, R21.2, TP2.1, U3.14 (VOS)
/Power Section/SW_L: L1.1, U3.1 (SW), U3.2 (SW), U3.3 (SW)
/Power Section/sw_status: D3.2 (A), R17.2, U2.1 (STAT)
/SW_BOOT0: R1.1, SW1.2 (B)
ADC_IN1: J13.4, U1.53 (PF13)
ADC_IN2: J13.2, U1.44 (PC4)
ADC_IN3: J13.3, U1.47 (PB1)
BAR_SCL: R28.1, U1.11 (PF1), U7.2 (SCK)
BAR_SDA: R27.1, U1.10 (PF0), U7.4 (SDI)
BAT_CURRENT: J1.4, U1.42 (PA6)
BAT_VOLTAGE: J1.3, U1.49 (PF11)
BUZZ: R36.2, U1.29 (PC3_C)
BUZZER-: J11.4, Q1.3 (D)
DEBUG_NRST: C15.1, J4.3 (~RESET), U1.25 (NRST)
DEBUG_SWCLK: J4.4 (SWCLK), U1.109 (PA14)
DEBUG_SWDIO: J4.2 (SWDIO), U1.105 (PA13)
DEBUG_SWO: J4.6 (SWO), U1.133 (PB3)
ESC_PWM1: J5.2, R7.1
ESC_PWM2: J5.3, R8.1
ESC_PWM3: J5.4, R9.1
ESC_PWM4: J5.5, R10.1
GND: C1.2, C2.2, C3.2, C4.2, C5.2, C6.2, C7.2, C8.2, C9.2, C10.2, C11.2, C12.2, C13.2, C14.2, C15.2, C16.2, C17.2, C18.2, C19.2, C20.2, C21.2, C22.2, C23.2, C24.2, C25.2, C26.1, C27.1, C28.1, C29.2, C30.1, C31.1, C32.1, C33.1, C34.1, C35.1, C36.2, C37.2, C38.2, C39.2, C40.2, C41.2, C42.1, C43.2, C44.2, C45.2, C46.2, C47.2, C48.2, C49.1, D1.1 (K), D2.2 (A), D3.1 (K), D4.1 (K), D5.2 (A), D6.1 (K), J1.1, J1.2, J1.7 (SHIELD), J1.8 (SHIELD), J2.9 (CARD_DETECT), J2.11 (GND), J2.12 (GND), J2.P6 (VSS), J3.A1 (GND), J3.B1 (GND), J3.SH1 (SHIELD), J3.SH2 (SHIELD), J3.SH3 (SHIELD), J3.SH4 (SHIELD), J4.5 (GND), J5.6, J5.7 (SHIELD), J5.8 (SHIELD), J6.4, J6.5 (SHIELD), J6.6 (SHIELD), J7.6, J7.7 (SHIELD), J7.8 (SHIELD), J8.6, J8.7 (SHIELD), J8.8 (SHIELD), J9.4, J9.5 (SHIELD), J9.6 (SHIELD), J10.1, J11.2, J11.6, J12.1, J13.5, MH1.1, MH2.1, MH3.1, MH4.1, Q1.2 (S), R15.1, R16.1, R20.1, R32.1, R34.1, R35.1, R37.1, SW1.3 (A), SW1.S1 (SHIELD), SW1.S2 (SHIELD), SW1.S3 (SHIELD), SW1.S4 (SHIELD), U1.16 (VSS), U1.31 (VSSA), U1.38 (VSS), U1.51 (VSS), U1.61 (VSS), U1.83 (VSS), U1.94 (VSS), U1.107 (VSS), U1.120 (VSS), U1.130 (VSS), U2.2 (EN_), U2.5 (GND), U2.9 (GND), U3.6 (GND), U3.7 (FSW), U3.8 (DEF), U3.15 (GND), U3.16 (GND), U3.17 (GND), U4.2 (NC), U4.3 (NC), U4.4 (GND), U4.6 (NC), U4.7 (NC), U4.9 (GND), U5.11 (RESV), U5.18 (GND), U5.20 (RESV), U6.9 (GND), U6.11 (GND), U7.3 (VSS), U7.8 (VSS), U7.9 (VSS), U8.3 (GND), Y2.2, Y2.4
GPIO_68: J12.4, U1.68 (PE15)
GPIO_69: J12.5, U1.69 (PB10)
GPIO_70: J13.1, U1.70 (PB11)
GPS_CAN_RX: J8.5, U1.114 (PD0)
GPS_CAN_TX: J8.4, U1.140 (PB9)
GPS_RX: J8.3, R5.2
GPS_TX: J8.2, R6.2
HSE_IN: C18.1, U1.23 (PH0), Y2.1
HSE_OUT: R3.1, U1.24 (PH1)
I2C_SCL: J9.2, R39.1, U1.136 (PB6)
I2C_SDA: J9.3, R38.1, U1.137 (PB7)
IMU_CS: R25.1, U1.22 (PF10), U5.22 (CS)
IMU_INT: U1.15 (PF5), U5.12 (INT1/INT)
IMU_MISO: U1.20 (PF8), U5.9 (SDO/AD0)
IMU_MOSI: U1.21 (PF9), U5.24 (SDA/SDI/SDIO)
IMU_SCK: U1.19 (PF7), U5.23 (SCL/SCLK)
MAG_CS: R26.1, U1.3 (PE4), U6.4 (SPI_CS)
MAG_INT: U1.8 (PC14), U6.15 (INT)
MAG_MISO: U1.4 (PE5), U6.5 (SPI_SDO)
MAG_MOSI: U1.5 (PE6), U6.16 (SDA/SPI_SDI)
MAG_SCK: U1.1 (PE2), U6.1 (SCL/SPI_SCK)
unnamed: C19.1, R3.2, Y2.3
unnamed: C20.1, U1.71 (VCAP)
unnamed: C21.1, U1.106 (VCAP)
unnamed: D1.2 (A), R4.2
unnamed: D4.2 (A), R22.1
unnamed: D5.1 (K), F1.2, J3.A4 (VBUS), J3.B4 (VBUS)
unnamed: D6.2 (A), R33.1
unnamed: J3.A5 (CC1), R34.2
unnamed: J3.B5 (CC2), R35.2
unnamed: Q1.1 (G), R36.1, R37.2
unnamed: R4.1, U1.122 (PD6)
unnamed: R5.1, U1.141 (PE0)
unnamed: R6.1, U1.142 (PE1)
unnamed: R7.2, U1.60 (PE9)
unnamed: R8.2, U1.64 (PE11)
unnamed: R9.2, U1.66 (PE13)
unnamed: R10.2, U1.67 (PE14)
unnamed: R16.2, U2.4 (ILIM)
unnamed: R14.1, R15.2, U2.3 (VSNS)
unnamed: R19.1, R20.2, U3.5 (FB)
unnamed: C29.1, U3.9 (SS/TR)
unnamed: R23.1, U4.5 (EN)
unnamed: C32.2, C33.2, R24.2, TP3.1, U4.1 (OUT)
unnamed: C38.1, U6.10 (CAP)
unnamed: R29.1, U7.5 (SDO)
PO_RX: J10.4, U1.37 (PA3)
PO_SCL: J10.5, R41.1, U1.54 (PF14)
PO_SDA: J10.6, R40.1, U1.55 (PF15)
PO_TX: J10.3, U1.36 (PA2)
PWR_GOOD: R18.1, U1.78 (PD9), U3.4 (PG)
RC_RX: J6.3, U1.97 (PC7)
RC_TX: J6.2, U1.96 (PC6)
RGB_LED_B: R13.1, U1.85 (PD14)
RGB_LED_G: R12.1, U1.82 (PD13)
RGB_LED_R: R11.1, U1.81 (PD12)
SD_CDS: C42.2, J2.10 (CARD_DETECT), R30.1, U1.117 (PD3)
SD_CLK: J2.P5 (CLK), U1.113 (PC12)
SD_CMD: J2.P3 (CMD), U1.116 (PD2)
SD_DAT0: J2.P7 (DAT0), U1.98 (PC8)
SD_DAT1: J2.P8 (DAT1), U1.99 (PC9)
SD_DAT2: J2.P1 (DAT2), U1.111 (PC10)
SD_DAT3: J2.P2 (DAT3/CD), U1.112 (PC11)
SWITCH: J11.5, R42.1, U1.2 (PE3)
TELEM_CTS: J7.4, U1.46 (PB0)
TELEM_RTS: J7.5, U1.75 (PB14)
TELEM_RX: J7.3, U1.35 (PA1)
TELEM_TX: J7.2, U1.34 (PA0)
UART5_RX: J12.2, U1.73 (PB12)
UART5_TX: J12.3, U1.74 (PB13)
USB_D+: J3.A6 (D1+), J3.B6 (D2+), U1.104 (PA12), U8.1 (D+)
USB_D-: J3.A7 (D1-), J3.B7 (D2-), U1.103 (PA11), U8.2 (D-)
USB_VBUS_SENSE: R31.1, R32.2, U1.101 (PA9)
VBUS: C26.2, C43.1, C44.1, F1.1, R31.2, R33.2, TP4.1, U2.6 (IN2)
VREF+_MCU: C16.1, C17.1, R2.2, U1.32 (VREF+)

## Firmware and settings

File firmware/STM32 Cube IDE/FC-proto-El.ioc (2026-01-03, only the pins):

Mcu.UserName=STM32H743ZITx
PA0.Signal=UART4_TX
PA1.Signal=UART4_RX
PA11.Signal=USB_OTG_FS_DM
PA12.Signal=USB_OTG_FS_DP
PA2.Signal=USART2_TX
PA3.Signal=USART2_RX
PA6.Signal=ADCx_INP3
PA9.Signal=USB_OTG_FS_VBUS
PB0.Signal=UART4_CTS
PB1.Signal=ADCx_INP5
PB10.Signal=GPIO_Output
PB11.Signal=GPIO_Output
PB12.Signal=UART5_RX
PB13.Signal=UART5_TX
PB14.Signal=UART4_RTS
PB6.Signal=I2C1_SCL
PB7.Signal=I2C1_SDA
PB9.Signal=FDCAN1_TX
PC10.Signal=SDMMC1_D2
PC11.Signal=SDMMC1_D3
PC12.Signal=SDMMC1_CK
PC3_C.Signal=GPIO_Output
PC4.Signal=ADCx_INP4
PC6.Signal=USART6_TX
PC7.Signal=USART6_RX
PC8.Signal=SDMMC1_D0
PC9.Signal=SDMMC1_D1
PD0.Signal=FDCAN1_RX
PD12.Signal=S_TIM4_CH1
PD13.Signal=S_TIM4_CH2
PD14.Signal=S_TIM4_CH3
PD2.Signal=SDMMC1_CMD
PD3.Signal=GPIO_Input
PD6.Signal=GPIO_Output
PD9.Signal=GPIO_Input
PE0.Signal=UART8_RX
PE1.Signal=UART8_TX
PE11.Signal=S_TIM1_CH2
PE13.Signal=S_TIM1_CH3
PE14.Signal=S_TIM1_CH4
PE15.Signal=GPIO_Output
PE2.Signal=SPI4_SCK
PE3.Signal=GPIO_Input
PE4.Signal=GPIO_Output
PE5.Signal=SPI4_MISO
PE6.Signal=SPI4_MOSI
PE9.Signal=S_TIM1_CH1
PF0.Signal=I2C2_SDA
PF1.Signal=I2C2_SCL
PF10.Signal=GPIO_Output
PF11.Signal=ADC1_INP2
PF13.Signal=ADC2_INP2
PF14.Signal=I2C4_SCL
PF15.Signal=I2C4_SDA
PF5.Signal=GPXTI5
PF7.Signal=SPI5_SCK
PF8.Signal=SPI5_MISO
PF9.Signal=SPI5_MOSI

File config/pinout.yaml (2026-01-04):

# Pinout configuration of the STM32H743ZIT6 MCU
# This file maps the various peripherals to their corresponding GPIO pins.

# Typycal descripton structure:
# stm32<MCU_MODEL>:
#   <PERIPHERAL_NAME>:  # <PERIPHERAL_DESCRIPTION>
#     <SIGNAL_NAME>: <PIN_NAME> (<PIN_COMMENT>)
#     ... 

# Matching v0.7 board as of 2025-01-04

stm32h743ZIT6:
  uart4:  #Telemetry
    tx:  PA0
    rx:  PA1
    cts: PB0
    rts: PB14

  uart5:  #Mini Pad Out UART
    tx: PB13
    rx: PB12

  uart8:    #GPS
    tx: PE1
    rx: PE0

  usart2:   #Pad Out USART
    tx: PA2
    rx: PA3

  usart6:   #RC Receiver
    tx: PC6
    rx: PC7

  spi4:   #Magnometer
    sck:  PE2
    miso: PE5
    mosi: PE6

  spi5:   #IMU
    sck:  PF7
    miso: PF8
    mosi: PF9

  i2c1:   #I2C Connector (ex: External Compass)
    sda: PB7
    scl: PB6

  i2c2:   #Barometer
    sda: PF0
    scl: PF1

  i2c4:    #Pad Out I2C
    sda: PF15
    scl: PF14

  fdcan1:   #GPS CAN Bus
    rx: PD0
    tx: PB9

  adc1:   #Battery Voltage/Current Sensor
    inp2: PF11   # ADC1_INP2 Voltage Sensor
    inp3: PA6    # ADCx_INP3 Current Sensor

  adc2:   #Pad Out ADCs 
    inp2: PF13   # ADC2_INP2
    inp4: PC4    # ADCx_INP4
    inp5: PB1    # ADCx_INP5

  tim1:  #Motors ESC PWM/DShot
    ch1: PE9    # S_TIM1_CH1 (PWM)
    ch2: PE11   # S_TIM1_CH2 (PWM)
    ch3: PE13   # S_TIM1_CH3 (PWM)
    ch4: PE14   # S_TIM1_CH4 (PWM)

  tim4:   #RGB LED
    ch1: PD12   # S_TIM4_CH1 (PWM) Red Channel
    ch2: PD13   # S_TIM4_CH2 (PWM) Green Channel
    ch3: PD14   # S_TIM4_CH3 (PWM) Blue Channel

  sdmmc1:   #SD Card
    d0:  PC8
    d1:  PC9
    d2:  PC10
    d3:  PC11
    ck:  PC12
    cmd: PD2
    cds: PD3  # Card Detect Switch

  usb_otg_fs:   #USB-C
    dm:   PA11
    dp:   PA12
    vbus: PA9

  sys_led:    #System Status LED
    pin: PD6

  ext_switch:   #External System Switch
    pin: PE3

  pwr_good:     #Power Good Signal (Buck 3V3 rail)
    pin: PD9

  buzzer:    #External Active Buzzer
    pin: PC3_C

  external_gpios:   #Pad Out GPIOs
    pin1: PE15  #GPIO_68
    pin2: PB10  #GPIO_69
    pin3: PB11  #GPIO_70

  debug:    #SWD Programming/Debugging Tag Conector
    swdio: "PA13 (JTMS/SWDIO)"
    swclk: "PA14 (JTCK/SWCLK)"
    swo:   "PB3 (JTDO/TRACESWO)"

  hse:    #Crystal Oscillator
    osc_in:  "PH0-OSC_IN (PH0)"
    osc_out: "PH1-OSC_OUT (PH1)"

  system:
    systick:    VP_SYS_VS_Systick
    memorymap:  VP_MEMORYMAP_VS_MEMORYMAP
    tim1_clock: VP_TIM1_VS_ClockSourceINT
    tim4_clock: VP_TIM4_VS_ClockSourceINT

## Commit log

2025-12-01 Schematic Upgrade
    [Component-Library.xlsx, FC-interfaces_sch.kicad_sch, FC-power-section.kicad_sch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]
2025-12-03 FC design 0.3
    [Component-Library.xlsx, FC-interfaces_sch.kicad_sch, PCM12SMTR.step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]
2025-12-10 FC design v0.5
    [Component-Library.xlsx, FC-interfaces_sch.kicad_sch, FC-proto.kicad_pcb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]
2025-12-10 FC design v0.5 corrected
    [Component-Library.xlsx, FC-interfaces_sch.kicad_sch, FC-proto.kicad_pcb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]
2025-12-16 Complete Routing
    [FC-interfaces_sch.kicad_sch, FC-proto.kicad_pcb]
2025-12-17 Top/Bot pours
    [FC-interfaces_sch.kicad_sch, FC-proto.kicad_pcb]
2025-12-18 Silkscreen improvements
    [FC-proto.kicad_pcb]
2025-12-23 Silkscreen Finish
    [Component-Library.xlsx, FC-proto.kicad_pcb]
2025-12-23 Silkscreen Finish*
    [FC-proto.kicad_pcb]
2026-01-03 Pinout / DRC check
    [FC-interfaces_sch.kicad_sch, FC-proto.kicad_pcb]
2026-01-04 power config improved
2026-01-18 changing USB ESD IC (v0.8)
    [Component-Library.xlsx, FC-interfaces_sch.kicad_sch, FC-proto.kicad_pcb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]
2026-02-22 Component library update
    [Component-Library.xlsx, FC-interfaces_sch.kicad_sch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]
2026-02-25 Component library fully complete
    [Component-Library.xlsx]
2026-02-25 Schematic update v0.9
    [Component-Library.xlsx, FC-interfaces_sch.kicad_sch]
2026-03-11 manufacturing exports v0.9
    [Component-Library.xlsx, FC-Dev-Board-v0.9-BOM.csv, FC-interfaces_sch.kicad_sch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]
2026-03-13 Pressure sensor replacement
    [Component-Library.xlsx, FC-Dev-Board-v0.9-BOM.csv, FC-Dev-Board-v0.9.5-BOM.csv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]
2026-03-21 Manufacturing v0.9.5
    [Component-Library.xlsx, FC-interfaces_sch.kicad_sch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]
